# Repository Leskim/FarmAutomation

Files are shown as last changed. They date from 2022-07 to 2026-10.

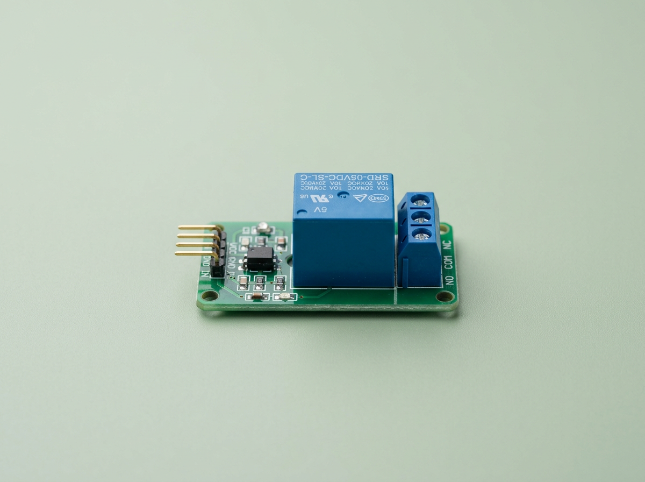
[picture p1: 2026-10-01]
public/images/pump-relay-module.png

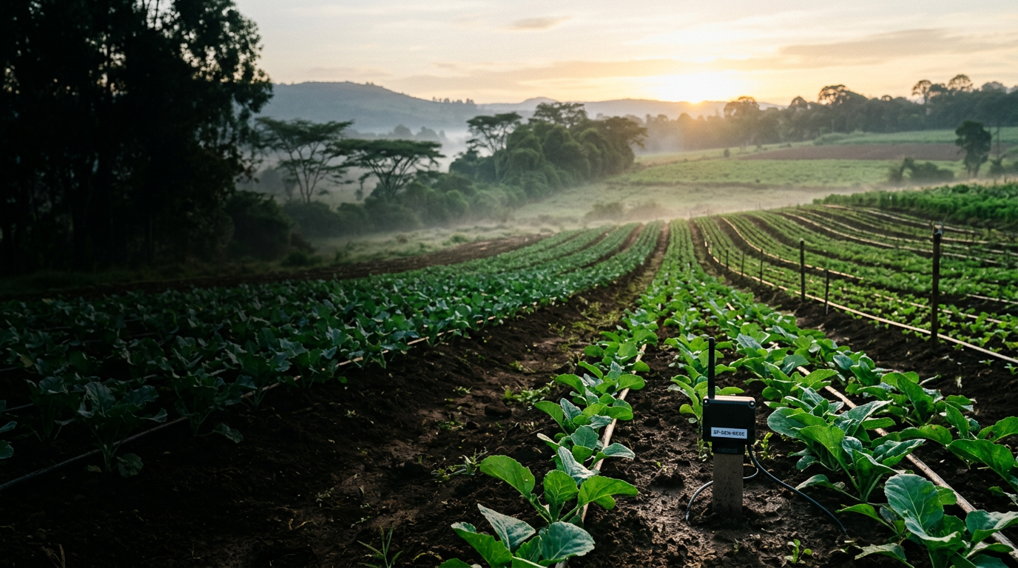
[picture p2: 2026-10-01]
public/images/farm-rows.png

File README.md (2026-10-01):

# Farm Automation

An open-source, small-scale irrigation prototype using soil-moisture and temperature/humidity readings, a Wi-Fi-connected controller, a Blynk dashboard, and a switched water pump. This repo includes Arduino sketches, a web showcase, project photos, dashboard/setup screenshots, and project video files.

## Hardware and costs

The supplied Novatech Inc. Nairobi cart screenshot lists these four items (shipping shown as free):

| Part in supplier screenshot | Quoted price |
| --- | ---: |
| Soil moisture sensor | KSh 150 |
| DHT11 temperature/humidity sensor | KSh 200 |
| ESP32 development board | KSh 750 |
| Mini DC submersible pump | KSh 300 |
| **Quoted total** | **KSh 1,400** |

The product description in the quote names an **ESP32**, while `NovaBlynky/blynkycode/blynkycode.ino` includes ESP8266/NodeMCU libraries. Check the exact board and firmware target before ordering; they are not interchangeable without changing the code. A relay or properly rated transistor/MOSFET driver is also required for pump switching and is not itemized in that cart (rough planning estimate on the showcase: KSh 250).

### Blue Pill and mobile-data alternative

The showcase uses estimated—not supplier-quoted—ranges of KSh 450–700 for a Blue Pill and KSh 850–1,500 for a SIM800L GSM/GPRS module.

- Replacing only the quoted KSh 750 Wi-Fi board with a Blue Pill would bring the four-item total to approximately **KSh 1,100–1,350**, a saving of **KSh 50–300 (about 4–21%)**. The Blue Pill itself has no Wi-Fi or cellular radio.
- Adding a SIM800L as the Blue Pill's network connection changes the estimate to approximately **KSh 1,950–2,850** for the quoted parts plus modem. That is **KSh 550–1,450 more** than the KSh 1,400 cart, before SIM/data, delivery, and a suitable modem power supply. Cellular adds coverage where Wi-Fi is absent; it does not make this build cheaper.
- SIM800L is a 2G GSM/GPRS modem. Check the current local carrier's 2G availability and coverage at the farm. Retarget the ESP8266 Blynk sketch for an STM32 UART and a compatible modem/Blynk library, and provide a regulated supply designed for the module's current bursts.

Alternative component prices shown on the website are rough comparison estimates, not live retailer offers. The named Novatech cart is the source for the KSh 1,400 total.

## Wiring and firmware walkthrough

1. Choose the sketch that matches the experiment. `Arduino Codes/moistureSenswithPump/moistureSenswithPump.ino` is a standalone soil-moisture/pump test; the Blynk sketch in `NovaBlynky/blynkycode/` reads the DHT11 and soil probe and exposes dashboard controls. They are separate sketches, not two files to flash together.
2. For the Blynk/NodeMCU sketch, the current code assigns the analog soil probe to `A0`, the DHT11 data line to GPIO2 (NodeMCU D4), and the pump-driver control to NodeMCU D2 (GPIO4). Confirm the board pinout before wiring and recalibrate the analog moisture threshold in the actual growing medium.
3. Copy `NovaBlynky/blynkycode/secrets.h.example` to `NovaBlynky/blynkycode/secrets.h` locally and replace the placeholders with the Blynk template ID, device name, token, Wi-Fi SSID/password, and setup-hotspot SSID/password. Both Blynk sketches use this private header; the nested sketch includes it from its parent folder. `secrets.h` is ignored by Git. **Keep Wi-Fi names, passwords, and the Blynk token hidden; never paste real values into a public sketch, screenshot, issue, or commit.**
4. In Blynk, create the device/template and datastreams used by the sketch: V4 humidity, V5 temperature, V6 pump switch, and V7 soil reading. Use the Blynk template/device credentials for that device in your local private header.
5. Install the matching ESP8266 board support and the Blynk and DHT libraries in Arduino IDE. Open the appropriate `.ino`, select the correct ESP8266/NodeMCU board and serial port, then compile and upload. Open Serial Monitor at 9600 baud to check readings and refine the moisture threshold before connecting a pump.
6. Keep the pump's motor current off the controller GPIO. Switch it with a relay or correctly rated driver, use a suitable separate pump supply, and follow the pump/driver wiring requirements. Keep a submersible pump underwater while running and protect electronics from splashes.
7. Configure and test the pump control while the system is supervised. Check the relay's active-high/active-low behavior and ensure the automatic threshold and Blynk manual switch cannot leave watering on unattended.

The Blynk sketch's virtual-pin mapping is V4 humidity, V5 temperature, V6 pump control, and V7 soil value. The `NovaBlynky/Screenshots/` folder documents sensor wiring, serial values, dashboard setup, and pump states.

## Viewing the project videos

The repository contains three LFS-tracked Blynk-project clips (about 244.7 MB, 234.9 MB, and 149.6 MB; roughly 629 MB combined). The website's featured clip is `NovaBlynky/VID20220520104322.mp4`, followed by the 10:46 and 10:48 clips. It streams from the GitHub media endpoint with `preload="none"`, so the full clip is not fetched until the visitor presses play. This supports byte-range requests but is not adaptive-bitrate video; playback can still pause on a slow or mobile connection.

For a separate 500 MB+ master video, the easiest smooth-playback option is **YouTube Unlisted**: upload the master, copy its video ID, and embed the YouTube player in the showcase. Unlisted videos are viewable by anyone with the link. YouTube automatically serves playback at suitable resolutions, avoiding a single huge MP4 download for site visitors. If you need a branded, controlled video host, use a managed streaming service such as Cloudflare Stream; it transcodes video and serves adaptive streaming. Keep the original master archived, and do not commit a 500 MB video directly to the site repository. Once you have the YouTube URL or ID, replace the GitHub video source with the corresponding `youtube-nocookie.com/embed/VIDEO_ID` player URL.

## Web showcase

The Next.js website presents the field build, quoted parts, cost comparisons, an automatically advancing/pauseable gallery made from six non-sensitive repository screenshots, and the original video playlist. Representative component-card images are illustrative product images; project photos and Blynk screenshots in the gallery show the actual build and recorded setup.

Run locally with Node.js installed:

```bash
npm install
npm run dev
```

Then open the local development URL printed by Next.js. To create a production build, run `npm run build`.

## Credential rotation notice

Earlier repository commits and a Blynk code screenshot contained real Wi-Fi/Blynk credential strings. The credential-bearing screenshot has been removed from the current tree; the gallery uses the safe setup screenshot instead. The sketches now use an ignored local secrets file, but these current-file changes do not erase values from Git history. **Rotate the Wi-Fi password and revoke/regenerate the Blynk device token before sharing or deploying this repository.** After rotating credentials, coordinate with anyone who has cloned the repo before purging old values from Git history; rewriting history changes commit IDs and requires collaborators to resync.

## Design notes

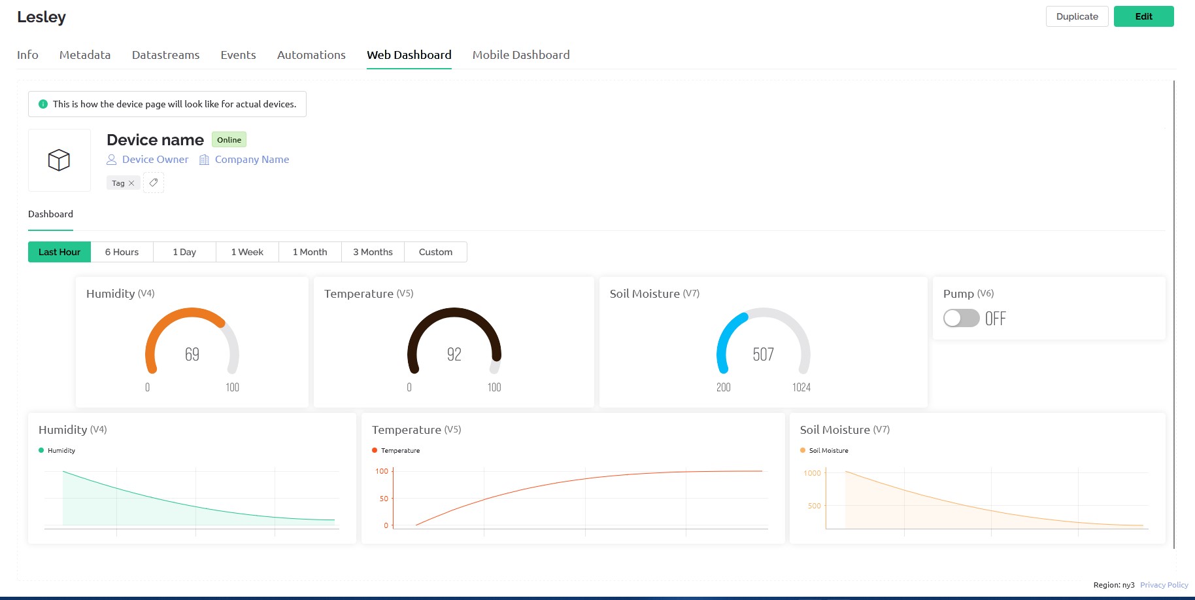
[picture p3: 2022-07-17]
public/images/blynk-dashboard.jpg

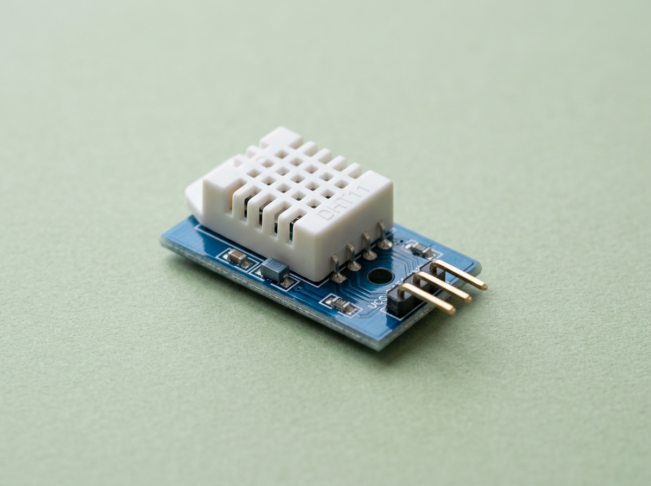
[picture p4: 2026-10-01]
public/images/dht11-module.png

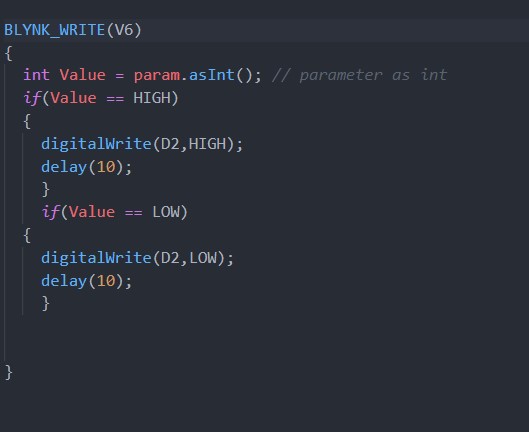
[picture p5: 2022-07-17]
public/images/pump-dashboard.jpg

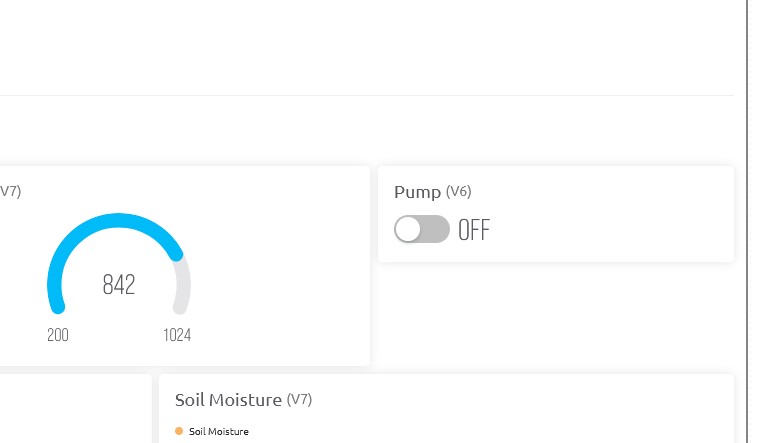
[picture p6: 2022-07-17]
public/images/pump-status.jpg

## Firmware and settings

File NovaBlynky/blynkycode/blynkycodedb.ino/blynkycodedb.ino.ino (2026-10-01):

#include "../secrets.h"

#define BLYNK_PRINT Serial
#include <ESP8266WiFi.h>
#include <BlynkSimpleEsp8266.h>

//To help connect to db
#include <ESP8266HTTPClient.h>
#include <Wire.h>
//#include <WiFi.h>
#include <WiFiClient.h>

WiFiClient wifiClient;

 
 const int Soil=A0;
 
#include <DHT.h>

char auth[] = BLYNK_AUTH_TOKEN;
char ssid[] = FARM_WIFI_SSID;  // KEEP HIDDEN: never publish your real Wi-Fi SSID or name.
char pass[] = FARM_WIFI_PASSWORD;  // KEEP HIDDEN: never publish your real Wi-Fi password.

#define DHTPIN 2          // Mention the digital pin where you connected 
#define DHTTYPE DHT11     // DHT 11  
DHT dht(DHTPIN, DHTTYPE);
BlynkTimer timer;

void sendSensor(){
  int moisture= analogRead(Soil);
  float h = dht.readHumidity();
  float t = dht.readTemperature(); // or dht.readTemperature(true) for Fahrenheit
  if (isnan(h) || isnan(t)) {
    Serial.println("Failed to read from DHT sensor!");
    return;
  }
    if (moisture > 600)
{
  digitalWrite(D2,HIGH);
  }
else
{
  digitalWrite(D2,LOW);
  }

  Serial.println(t);
  Blynk.virtualWrite(V7, moisture);
  Blynk.virtualWrite(V4, h);
  Blynk.virtualWrite(V5, t);
    Serial.print("Temperature : ");
    Serial.println(t);
    Serial.print("    Humidity : ");
    Serial.println(h);
Serial.print("    Moisture : ");
    Serial.println(moisture);

  if(t > 30){
   // Blynk.email("shameer50@gmail.com", "Alert", "Temperature over 28C!");
    Blynk.logEvent("temp_alert","Temp above 30 degree");
  }


//  Connect to db
String sendtemp, sendhum, sendsoil, postData;
HTTPClient http; // http object of class HTTPClient
// Convert to float
  sendtemp = t;
  sendhum = h;
  sendsoil = float(moisture); 
  postData = "sendtemp=" + sendtemp + "&sendhum=" + sendhum + "&sendsoil" + sendsoil;

  // We can post values to PHP files as  example.com/dbwrite.php?name1=val1&name2=val2
  // Hence created variable postData and stored our variables in it in desired format
  // Update Host URL here:-
  http.begin( wifiClient, "http://192.168.0.18/fourthyearProj/farmsens.php");  // Connect to host where MySQL database is hosted
  http.addHeader("Content-Type", "application/x-www-form-urlencoded");  //Specify content-type header
  int httpCode = http.POST(postData);   // Send POST request to php file and store server response code in variable named httpCode
  Serial.println("Values are, sendtemp = " + sendtemp + ", sendhum " + sendhum +  " and sendsoil = "+sendsoil );
  // if connection eatablished then do this
  if (httpCode == 200) { Serial.println("Values uploaded successfully."); Serial.println(httpCode);
    String webpage = http.getString();  // Get html webpage output and store it in a string
    Serial.println(webpage + "\n");
  } else {
    // if failed to connect then return and restart
    Serial.println(httpCode);
    Serial.println("Failed to upload values. \n");
    http.end();

//Connect to Database


}
}

BLYNK_WRITE(V6)
{
  int Value = param.asInt(); // parameter as int 
  if(Value == HIGH)
  {    
    digitalWrite(D2,HIGH);
    delay(10);
    }  
    if(Value == LOW)
  {
    digitalWrite(D2,LOW);
    delay(10);
    } 

   
}

void setup(){
   Serial.begin(9600);
  Blynk.begin(auth, ssid, pass);
   pinMode(D2,OUTPUT);
  dht.begin();
  timer.setInterval(2500L, sendSensor);
  WiFi.begin();
  WiFi.mode(WIFI_AP);
 WiFi.softAP(FARM_AP_SSID, FARM_AP_PASSWORD); // KEEP HIDDEN: never publish the real hotspot password.
 while (WiFi.softAPgetStationNum() !=1){ //loop here while no AP is connected to this station
      Serial.print(".");
      delay(100);                           
      }
}



void loop(){
  Blynk.run();
  timer.run();
}

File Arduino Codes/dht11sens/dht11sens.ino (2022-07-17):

//Include sensor library DHTLib `think from adafruit` so as to use the Sensor.read11 property

#include <dht.h>

//Define the sensor pin as 8
#define DHT11_PIN 8 
//Call dht on sensor to use logics
dht Sensor;
void setup() {
//  Set serial monitor
  Serial.begin(9600);
  Serial.println(F("DHT11!"));
}
void loop() {


  Sensor.read11(DHT11_PIN);

//  If not abble to get sensor readings 
  if (isnan(Sensor.humidity) || isnan(Sensor.temperature) || Sensor.humidity < 0 ) {
    Serial.println(F("Failed to read from DHT sensor!"));
    delay (2000);
    return;
  }
//  delay(100);
//Print humidity and temp with 2s delay
  Serial.print("Humidity: ");
  Serial.print(Sensor.humidity);
  Serial.println(" %");
  Serial.print("Temperature: ");
  Serial.print(Sensor.temperature);
  Serial.println(" C");
  delay(2000);


}

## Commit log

2022-02-23 Added working soilmoisture sensor code with pump logic at 0% moisture level though
2022-02-23 Added video to show moisturesensor plus pump logic working
2022-02-23 Adding dht11sensor working arduino code
2022-02-23 Adding Fritzing schematics
    [FritzingSchematics.fzz]
